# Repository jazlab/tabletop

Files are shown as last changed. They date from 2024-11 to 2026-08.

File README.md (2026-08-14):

# TableTop

TableTop is a [ROS 2](https://docs.ros.org/en/jazzy/index.html)-based robotics
platform for controlling one or more Universal Robots UR5e arms in a monkey
electrophysiology research rig. It runs entirely in [Docker](https://www.docker.com/)
containers and uses [MoveIt 2](https://moveit.picknik.ai/) for motion planning.

The system presents physical objects to a subject, measures their responses
(button presses, eye gaze), delivers rewards, and records synchronized sensor
and robot-state data (via ROS 2 Bag files) for offline analysis. It also ships a
virtual tabletop environment for simulation and system testing, plus
post-processing tools for motion correction, spike sorting, NWB conversion, and
gaze estimation.

## Documentation

**Full documentation lives at <https://jazlab.github.io/tabletop/>.** Start there
for the project overview, setup, usage, and troubleshooting:

- **[Setup](https://jazlab.github.io/tabletop/getting-started/setup/)** — clone,
  configure the host, and bring up the containers.
- **[Real Hardware Setup](https://jazlab.github.io/tabletop/getting-started/real-hardware/)**
  — the TableTop network, URCaps, and remote control.
- **[Usage](https://jazlab.github.io/tabletop/getting-started/usage/)** — build,
  start containers, and run a task.
- **[Design Choices](https://jazlab.github.io/tabletop/design-choices/)** — why
  ROS 2, MoveIt 2, and Docker.
- **[Architecture](https://jazlab.github.io/tabletop/architecture/)** — the
  conceptual dependency map and where to look when something breaks.
- **[Guide](https://jazlab.github.io/tabletop/guide/cli/)** — CLI tooling,
  configuration, the task system, hardware & safety, and troubleshooting.
- **[API Reference](https://jazlab.github.io/tabletop/reference/)** —
  auto-generated for `tabletop_py`, `tabletop_rig`, and `tabletop_tasks`.

The same pages live as Markdown under [`docs/`](docs/) if you prefer to read them
in the repository.

## Quick start

```bash
# Clone with submodules
git clone --recurse-submodules https://github.com/jazlab/tabletop.git
cd tabletop

# Source the environment (puts the tt-* commands on your PATH)
source setup.bash
```

See [Setup](https://jazlab.github.io/tabletop/getting-started/setup/) for the
full host configuration (Docker, `uv`, `.env` generation) and
[Usage](https://jazlab.github.io/tabletop/getting-started/usage/) for building
and launching.

## Contributing

Contributions are welcome. Fork the repo, install the dev dependencies
(`uv sync`) and pre-commit hooks (`pre-commit install`), make your changes on a
branch, and open a pull request. Python follows `ruff` formatting (79-char
lines, Google-style docstrings); pre-commit runs the linters automatically on
commit. Please follow the
[ROS 2 contribution guidelines](https://docs.ros.org/en/jazzy/The-ROS2-Project/Contributing.html).

Notebooks under `notebooks/` are committed **without outputs** — `nbstripout`
clears cell outputs and execution counts on commit, so embedded plots don't
bloat the repo or produce unreadable diffs. If a commit is rejected with
`nbstripout ... files were modified by this hook`, the notebook has just been
stripped in place: `git add` it again and re-commit. Re-running the notebook
locally to restore the outputs is fine; they just don't get committed.

## License

[MIT](LICENSE)

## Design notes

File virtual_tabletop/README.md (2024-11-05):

# Virtual TableTop Model

## Introduction

This directory has code to create a virtual model of the TableTop environment in
Mujoco. It is currently in draft mode and there are several things to do going
forward:
1. Flesh out the rig model with all the parts of the rig.
2. Allow this virtual tabletop to load logs from a session and simulate the
robot, rig, and monkey based on those logs.
3. Adapt the monkey arm model to the geometry of our monkeys.

## Usage

Set up by following these steps:
1. Clone this repo locally.
2. Create a virtual environment to manage dependencies.
3. Install requirements by navigating the this directory and running
   `$ pip install -r requirements.txt`.
4. Run the virtual tabletop model with `$ python run_tabletop.py`.

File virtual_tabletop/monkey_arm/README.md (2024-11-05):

# Model Monkey Arm

This model monkey arm was forked and modified from the Saxena Lab muSim
musculoskeletal model (https://github.com/saxenalab-neuro/muSim).

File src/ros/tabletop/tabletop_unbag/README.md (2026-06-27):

# tabletop_unbag

A generic ROS 2 bag (MCAP) → CSV / image exporter, written in C++. It is a port
of the Python `tabletop_rig.utils.rosbag` module, but runs as a standalone,
dependency-light executable (`unbag`) with no Python / pandas / rclpy at
runtime, and is built to stream very large bags without exhausting memory.

It is **multithreaded**: a single reader thread feeds one consumer thread per
CSV topic and a shared pool of worker threads that decode images in parallel, so
the (CPU-bound) image transcoding scales across all cores. On a 24-core machine
this is roughly a 10× end-to-end speedup over the single-threaded version, while
peak memory stays bounded by back-pressure on the work queues.

## What it does

Given a *bag directory* (the directory that holds the `.mcap` files and
`metadata.yaml`), `unbag` writes one output per topic into an output directory
(by default `<parent of BAG_DIR>/unbag`):

* **Normal messages** are flattened into a per-topic CSV
  (`/eyelink/sample` → `eyelink_sample.csv`). Any message type works — there is
  no per-type code. Nested submessages become dot-separated columns
  (`pose.position.x`) and array / sequence elements become bracket-indexed
  columns (`name[0]`, `position[2]`). Every row carries a `bag_time_ns` column,
  and the columns are the union of every field seen across the topic's messages
  (shorter messages leave trailing columns empty).
* **Image topics** (`sensor_msgs/msg/Image`,
  `sensor_msgs/msg/CompressedImage`) are decoded and saved as image files under
  a per-topic subdirectory (`<topic>/<sec>_<nanosec>.{jpg,png,tiff}`). The `sec`
  and `nanosec` fields are zero-padded to a fixed width (10 and 9 digits) so the
  files sort chronologically under a plain lexicographic sort. When more
  than one frame shares a header stamp (e.g. synchronized cameras), the extra
  frames are kept under a zero-padded suffix
  (`<sec>_<nanosec>_<NNN>.<ext>`) assigned in bag-receive order, so no frame is
  lost and the files still sort chronologically. `--image-format` controls the
  output file format.

## Usage

```bash
# Unbag everything into <parent of BAG_DIR>/unbag
ros2 run tabletop_unbag unbag /path/to/session/bag

# Choose the output directory
ros2 run tabletop_unbag unbag /path/to/session/bag -o /path/to/out

# Only the CSV handler (skip image topics), or only the image handler
ros2 run tabletop_unbag unbag BAG_DIR --handlers csv
ros2 run tabletop_unbag unbag BAG_DIR --handlers image --image-encoding mono8

# Save every image as PNG (lossless) instead of keeping the source format
ros2 run tabletop_unbag unbag BAG_DIR --handlers image --image-format png

# Restrict / exclude topics (mutually exclusive)
ros2 run tabletop_unbag unbag BAG_DIR --topics /joint_states /predicted_markers
ros2 run tabletop_unbag unbag BAG_DIR --exclude-topics /rosout

# Re-run from scratch instead of resuming
ros2 run tabletop_unbag unbag BAG_DIR --overwrite
```

Handler-specific options are namespaced by handler (`--csv-*`, `--image-*`) so it
is clear which handler each one affects; run-wide options have no prefix.

**Common options**

| Flag | Description |
| --- | --- |
| `BAG_DIR` (positional) | Directory containing the bag's `.mcap` files and `metadata.yaml`. Required. |
| `-o, --output-dir DIR` | Where to write outputs. Default: `<parent of BAG_DIR>/unbag`. |
| `--handlers H [H ...]` | Handlers to enable (`csv`, `image`). Topics whose type is not claimed by an enabled handler are skipped. Default: all. |
| `--topics T [T ...]` | Only unbag these topics. Mutually exclusive with `--exclude-topics`. |
| `--exclude-topics T ...` | Unbag all topics except these. Mutually exclusive with `--topics`. |
| `--overwrite` | Delete previously unbagged output for the selected topics before writing. Without it, an interrupted run resumes. |
| `--jobs N` | Worker threads in the shared image-decoding pool (default: number of hardware threads). Each CSV topic additionally runs on its own consumer thread. |
| `--opencv-threads N` | Threads OpenCV uses internally per image decode (default `1`). We already parallelize across images via `--jobs`, so `1` avoids oversubscribing cores; `0` lets OpenCV choose. Tune against `--jobs` for your machine. |
| `--storage-id ID` | Storage plugin override. Default: inferred from `metadata.yaml`; if that file is missing the bag is reindexed first and the id read back from the rebuilt metadata, then falling back to the installed default plugin (`mcap` on a stock Jazzy install). |
| `-v, --verbose` | Log the handler chosen for each topic, topics skipped, and per-topic success/failure counts in the end-of-run summary. |

**`csv` handler options**

| Flag | Description |
| --- | --- |
| `--csv-batch-size N` | Rows buffered in memory before flushing to disk (default 1000). |

**`image` handler options**

| Flag | Description |
| --- | --- |
| `--image-encoding ENC` | Target *color* encoding for decoded images (default `bgr8`; e.g. `rgb8`, `mono8`). |
| `--image-format FMT` | Output *file* format: `keep` \| `png` \| `jpg` \| `tiff` (default `keep`). `keep` preserves the source container (a `CompressedImage` keeps its compression, a raw `Image` is written as PNG); a specific format applies to every image topic (`png` avoids a lossy re-encode of compressed Bayer topics). |

The storage plugin is inferred from the bag's `metadata.yaml`; if that file is
missing or corrupted it is rebuilt with the rosbag2 reindexer and the storage id
read back from the result. `--storage-id` is only needed when that inference is
unavailable or wrong (and seeds the reindexer when no metadata exists). There is
no `--serialization-format` flag: the reader determines each message's input
serialization from the per-topic metadata, and the converter always targets CDR
for the deserializers, so the format is not something the user picks.

After the write pass, `unbag` prints a one-line summary of how many messages were
successfully unbagged versus dropped (a decode/flatten/write failure), with a
per-topic breakdown for any topic that had failures (and for every topic under
`--verbose`). Failures are usually all-or-nothing per topic, so a partial count
is a useful signal that something is off with that topic.

## Architecture

Each message type is routed to a **handler**. Handlers live in `handlers/` and
derive from `MessageHandler` (`handlers/handler.hpp`); a small dispatch in
`unbagger.cpp` picks, per topic, the first handler that claims the message type
(the image handler is checked before the CSV catch-all). Adding support for a
new output type is a matter of adding a handler and registering it.

```text
include/tabletop_unbag/
├── options.hpp            # UnbagOptions, TopicInfo
├── progress_bar.hpp       # tqdm-style progress bar (header-only, no deps)
├── concurrent_queue.hpp   # bounded blocking queue (reader <-> workers)
├── unbagger.hpp           # unbag(): metadata inference + dispatch + the passes
└── handlers/
    ├── handler.hpp        # MessageHandler base (the handler lifecycle)
    ├── csv_handler.hpp
    └── image_handler.hpp
src/
├── main.cpp               # CLI
├── unbagger.cpp           # orchestration + the threaded pipeline
└── handlers/
    ├── csv_handler.cpp    # flattening + pandas-compatible value formatting
    └── image_handler.cpp  # cv_bridge / Bayer decode (thread-safe, atomic writes)
```

### The handler lifecycle (two passes, batched, resumable)

The orchestrator drives every handler through the same lifecycle, which is what
lets it stay type-agnostic:

1. **Preprocess pass** — `preprocess()` is called once per message, but only for
   handlers whose `needs_preprocess()` is true. The CSV handler needs it to
   learn the column set: a `sequence<>` field's length is only known per
   message, so the column union cannot be known without reading every message
   first. It stores only column *names* (O(#columns) memory), not rows. The
   image handler does not need it (each image is independent), so its
   `preprocess()` is a no-op and — when no enabled handler needs the pass — the
   whole pass is skipped. This pass also pushes a topic filter into the storage
   reader so only the CSV topics are read: the bulk of a bag is usually image
   data, and there is no reason to read (or decode) it just to learn columns.
2. **`begin_write()`** — handlers apply the overwrite/resume policy.
3. **Write pass** — `write()` is called once per message; handlers buffer and
   flush in batches (the CSV handler's batch is sized by `--csv-batch-size`), so
   memory stays bounded no matter how many messages a topic has.
4. **`finish()`** — flush and close.

**Interruption / resume.** Because output is flushed incrementally, an
interrupted run leaves valid partial output. Re-running (without `--overwrite`)
picks up where it left off: the CSV handler counts the rows already on disk
(repairing a torn final line) and skips that many messages before appending; the
image handler skips timestamps whose file already exists. `--overwrite` instead
deletes the selected topics' prior output first — the CSV handler removes its
file, and the image handler clears the topic's directory so a re-run with a
different `--image-encoding` cannot leave a mix of old and new formats behind.

### Parallelism and back-pressure

A bag is read once per pass by a single reader thread (rosbag2's reader is
sequential), but the per-message work is fanned out:

* **Across topics.** Each CSV topic gets its own bounded queue and consumer
  thread, so different topics' files are flattened and written concurrently.
  Rows stay in bag order because a topic's messages flow through one FIFO queue
  to one consumer.
* **Across messages, for images.** Image messages from every image topic go to a
  single shared queue drained by a pool of `--jobs` worker threads. Each image is
  decoded, demosaiced and encoded independently and written to its own file, so
  this scales across cores — and image transcoding is by far the most expensive
  part of unbagging a camera-heavy bag. (CSV rows are *not* parallelized within a
  topic: they share one file and must stay ordered, and CSV work is cheap enough
  that one thread per topic already keeps up with the reader.)

The queues are **bounded**, which does double duty: it caps memory (the reader
cannot race ahead and buffer the whole bag), and it makes the reader
self-throttle to the slowest consumer — when the image pool is saturated the
reader simply blocks on `push()` instead of piling up work.

Shutdown is the same on success and on Ctrl-C. A `SIGINT`/`SIGTERM` handler sets
a stop flag; the reader stops, closes the queues, and the workers drain whatever
is already queued and exit before the handlers flush and close. Combined with
atomic image writes (each image is encoded to memory, written to a temp file,
then `rename`d into place) and the CSV torn-line repair, an interrupted run never
corrupts an output file and always resumes cleanly. The input bag is opened
read-only and is never written to.

### Generic flattening

The Python version relies on rclpy's dynamically generated message classes and
`get_fields_and_field_types()`. C++ messages are statically typed, so the CSV
handler instead loads the `rosidl_typesupport_introspection_cpp` description of
each type at runtime and reads the CDR payload directly with Fast CDR (ROS 2
serializes messages as PLAIN_CDR / XCDRv1). This is RMW-independent (it does not
go through `rmw_deserialize`), so it works regardless of the active middleware.
Values are formatted to match pandas' `to_csv` output: shortest round-tripping
floats with a trailing `.0` on integral values, `True`/`False` for booleans, and
RFC 4180 minimal quoting for strings.

### Image decoding

Color conversion goes through **cv_bridge** for uncompressed `Image` messages
and for non-Bayer `CompressedImage` messages, so any target encoding cv_bridge
supports works (set with `--image-encoding`). The one case cv_bridge cannot
handle is a **compressed Bayer** image: the FLIR cameras JPEG-compress the raw
single-channel Bayer mosaic (format e.g. `bayer_rggb8; jpeg compressed
bayer_rggb8`), and cv_bridge infers a compressed image's encoding from its
channel count, so it would mistake the mosaic for `mono8` and never demosaic.
For that case the handler parses the `format` string and demosaics with the
Bayer-aware OpenCV conversion codes (ROS and OpenCV name Bayer patterns from
opposite corners, hence the swapped-looking codes). Uncompressed Bayer is fine
through cv_bridge, which knows the source encoding from `msg.encoding`.

### One intentional difference from the Python version

The Python flattener expands variable-length sequences but, due to a quirk of
its `sequence<...>` type-string check, collapses **fixed-size primitive arrays**
(e.g. `CameraInfo.k`, a `float64[9]`) into a single column holding a numpy
string like `[600. 0. 320. ...]`. This port expands fixed-size arrays the same
way as sequences (`k[0]..k[8]`), which is the more useful and presumably
intended behavior. All other CSV output is byte-for-byte identical to the Python
converter (verified by diffing both on the same bag).

## Building

```bash
tt-build colcon -p tabletop_unbag
# or, directly:
colcon build --packages-select tabletop_unbag
```

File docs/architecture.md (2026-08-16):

# TableTop System Architecture

A conceptual dependency map of the TableTop platform: how the pieces fit
together, who talks to whom, and where to look when something breaks.
Intended for new users, developers, and agents navigating the codebase.

> Scope: the core platform (`bin/`, `compose.yaml`, `src/tabletop_py`,
> `src/ros/tabletop/*`). External forks in `src/ros/modules/` and the
> `virtual_tabletop/` MuJoCo simulation are out of scope.

## 1. The Big Picture

The system is layered. Each layer only reaches *down*:

```text
┌──────────────────────────────────────────────────────────────────┐
│ EXPERIMENTS   tabletop_tasks: ForagingTask, SmoothPursuitTask, … │
│               (YAML task configs → trial generators → trials)   │
├──────────────────────────────────────────────────────────────────┤
│ ORCHESTRATION tabletop_rig Commander node                        │
│               (aggregates interfaces: MoveIt, Teensy, Flic,      │
│                Eyelink, UR dashboard, Sound)                     │
├──────────────────────────────────────────────────────────────────┤
│ DEVICE NODES  one ROS 2 node per device, one Docker container    │
│               per node: ur driver, teensy (micro-ROS), flic,     │
│               eyelink, flir cameras, optitrack, rosbag           │
├──────────────────────────────────────────────────────────────────┤
│ ROS PLUMBING  tabletop_interfaces (msgs/srvs/actions),           │
│               tabletop_description (URDF), tabletop_moveit_config│
├──────────────────────────────────────────────────────────────────┤
│ PURE PYTHON   tabletop_py: gaze ML, flic protocol, utils         │
│               (no ROS dependency; imported by the layers above)  │
├──────────────────────────────────────────────────────────────────┤
│ INFRA         bin/ scripts → compose.yaml services → Docker      │
│               (.env generated by tt-env-gen; setup.bash env)     │
└──────────────────────────────────────────────────────────────────┘
```

All containers share `network_mode: host` and `ipc: host`, so every ROS
node sees every other node regardless of which container it runs in.

## 2. Infrastructure Layer

### 2.1 Environment flow

```text
setup.bash ──(sourced by every script & container entrypoint)──▶ env vars
    │            TABLETOP_DIR, COLCON_WS, ROS_LOG_DIR, ROBOT_IP…
    ▼
tt-env-gen ──▶ .env  (from .env.example; detects FLIR devices and the
    │                 PulseAudio socket; derives the GPU vars from the
    │                 user-set COMMANDER_RUNTIME)
    ▼
tt-compose ──▶ docker compose (compose.yaml reads .env for devices,
                runtimes, mounts)
```

- `setup.bash` is the single source of environment truth. It detects
  host-vs-container via `TABLETOP_CONTAINER`, activates the right uv
  venv (`.venv` host / `.venv.container` container), sources ROS, and
  puts `bin/common` + `bin/host` or `bin/container` on `PATH`.
- `.env` must be regenerated (`tt-env-gen`) whenever hardware changes
  (cameras/Teensy plugged in) because device paths are baked into it, and
  whenever `COMMANDER_RUNTIME` changes because `UV_EXTRA` and the `NVIDIA_*`
  variables are derived from it. The container runtime is opt-in, not
  autodetected — see
  [Configuration](guide/configuration.md#gpu-access-nvidia-container-runtime).

### 2.2 `bin/` scripts — what each one actually runs

| Script | Where | Under the hood |
| --- | --- | --- |
| `host/tt-compose` | host | `tt-env-gen` (if no `.env`) then `docker compose "$@"` |
| `host/tt-env-gen` | host | regenerates `.env` from `.env.example`; scans `/dev/flir/` and PulseAudio; expands `COMMANDER_RUNTIME` into `UV_EXTRA`/`NVIDIA_*` |
| `host/tt-build` | host | `tt-env-gen` then `docker compose run --rm builder tt-build "$@"` |
| `host/tt-attach` | host | `tt-env-gen` then `docker compose run --rm <svc> [/entrypoint.sh] bash` (or `exec` with `-e`); does **not** start the service |
| `host/tt-flir-reset` | host | `tt-env-gen` → stop flir svc → reload udev → `docker compose run --rm flir tt-launch flir_no_sync factory_reset:=true` → restart |
| `container/tt-build` | container | dispatches on `<colcon\|microros\|foxglove>`: colcon (`uv sync` + `colcon build`), microros (PlatformIO `pio run`), foxglove (`npm run package` → `.foxe` to `$TABLETOP_DIR` or `-o` path) |
| `container/tt-launch` | container | case-routes to `ros2 launch <pkg> <name>.launch.py`, sets per-target `ROS_LOG_DIR` |
| `container/tt-kill-ros` | container | `pkill -f ros` |
| `common/tt-clean` | both | `rm -rf` of build/install/log/cache dirs by flag |

Host configuration for real hardware (udev rules, USB buffer size, CPU governor,
the TableTop network, URCaps) is no longer shipped as `scripts/configure/`
scripts; it is documented as Ubuntu 24.04 procedures in
[Real Hardware Setup](getting-started/real-hardware.md).

### 2.3 Compose services × profiles

| Service | Profile(s) | Command | Devices / special |
| --- | --- | --- | --- |
| `ros-base` | template | — (extends-only) | bind-mounts repo at `/tabletop`; parent of all ROS services, never run directly |
| `commander` | commander | `tt-launch commander` | `$COMMANDER_RUNTIME` (GPU when set to `nvidia`), PulseAudio, bags mount |
| `ur` / `ur-mock` | real / sim | `tt-launch dual_ur robot_mode:=real\|mock` | rtprio ulimits |
| `teensy` / `teensy-sim` | real / sim | `tt-launch teensy simulate:=false\|true` | `$TEENSY_DEV` serial |
| `flic` / `flic-sim` | real / sim | `tt-launch flic simulate:=false\|true` | `NET_ADMIN` (BLE sniffing) |
| `eyelink` / `eyelink-sim` | real / sim | `tt-launch eyelink simulate:=…` | bags mount |
| `flir` | real | `tt-launch flir_synchronized` | `$FLIR_DEV_0..5` USB devices |
| `optitrack` | real | `tt-launch optitrack` | |
| `rviz`, `foxglove` | real, sim | `tt-launch rviz\|foxglove` | rviz renders to noVNC display |
| `novnc` | real, sim | X11+VNC server | browse to `localhost:<NOVNC_PORT>/vnc.html` |
| `builder` | builder | — (set at run time) | privileged, `/dev`, platformio cache volume; target of host `tt-build` |
| `dev` | dev | `sleep infinity` | the Dev Container; everything mounted |

A typical real-hardware session: `tt-compose --profile=real up` starts
ur + teensy + flic + eyelink + optitrack + flir + rviz + novnc, then
`tt-compose run --rm commander tt-launch tasks task:=…` runs a commander
container on top.

## 3. ROS Runtime Graph

Who talks to whom at runtime (solid = topic, dashed = service/action):

```mermaid
graph LR
    subgraph commander container
        CMD[commander node]
    end
    subgraph device containers
        UR[ur driver + controller_manager]
        TEENSY[teensy micro-ROS agent ⇄ Teensy 4.1]
        FLIC[flic node]
        EYE[eyelink node]
        FLIR[cam_sync node]
        OPTI[optitrack_driver]
        BAG[rosbag recorder]
    end

    TEENSY -- "teensy/sensor (TeensySensor)" --> CMD
    CMD -. "teensy/set_arm_lock, set_reward,<br>set_smartglass, set_solenoid" .-> TEENSY
    CMD -. "flic/response_time (action)" .-> FLIC
    CMD -. "eyelink/smooth_pursuit (action)" .-> EYE
    EYE -- "eyelink samples" --> BAG
    CMD -. "left|right dashboard srvs,<br>controller_manager srvs" .-> UR
    UR -- "joint_states, robot_description" --> CMD
    CMD -- "trajectory execution (MoveIt)" --> UR
    FLIR -- "cam_sync/<cam>/image_raw, meta" --> BAG
    OPTI -- "rigid body poses" --> BAG
```

Key edges:

- **Safety loop**: Teensy firmware publishes `teensy/sensor` (at a configurable
  rate); `TeensyInterface` (inside Commander) gates every robot motion through
  `safe_to_execute`. The safety-laser field is always enforced; the arm-lock
  check (both restraints seated) is gated by the
  `safe_to_execute.require_arm_locks` parameter in `commander.yaml`, which
  defaults to `false` (laser-only) — set it `true` to also require the arm
  locks. See [Hardware & Safety](guide/hardware.md#safety-interlock).
- **Hardware sync**: the Teensy emits a hardware trigger pulse wired to
  the FLIR cameras' Line0, so all cameras expose simultaneously; the
  synchronized driver stamps grouped frames identically.
- **MoveIt runs inside the Commander process** (`moveit_py`), not as a
  separate `move_group` node — planning is in-process, execution goes
  to the UR `controller_manager` action servers.

## 4. Launch & Configuration

### 4.1 Launch hierarchy

There is **no monolithic aggregator launch file**. The old `rig.launch.py`
(which bundled every subsystem behind `*_launch:=true|false` toggles) was
retired to `deprecated/launch/rig.launch.py`; each subsystem now runs in its
own Compose service, launched by its own `tt-launch <target>` (see §2.3). The
only launch file that *includes* others is `tasks.launch.py`, which now pulls in
just the commander and (optionally) the recorder:

```text
tasks.launch.py (tabletop_tasks)         task:=<name> ⇒ coro_config=config/<name>.yaml
├── commander.launch.py (tabletop_rig)   → commander node (+ moveit_cpp config),
│                                           runs run_tasks(coro_config)
└── rosbag.launch.py (tabletop_rig)       → ros2 bag record (topics from rosbag.yaml)
                                            [only if rosbag:=true — see note below]

# Each of the following is its own tt-launch target / Compose service:
commander.launch.py        → commander node alone (no task)
dual_ur.launch.py          → ur driver stack (both arms)
    └── dual_rsp.launch.py (tabletop_description) → robot_state_publisher (URDF)
teensy.launch.py           → micro_ros_agent | mock_teensy (simulate:=true)
flic.launch.py             → flic node
eyelink.launch.py          → eyelink node
optitrack.launch.py        → mocap4r2 lifecycle driver
flir.launch.py             → per-camera CameraDriver components (unsynchronized)
flir_synchronized.launch.py→ SynchronizedCameraDriver component
flir_calibrate.launch.py   → FLIR calibration capture
rviz.launch.py             → rviz2 (waits for robot_description)
rosbag.launch.py           → ros2 bag record (topics from rosbag.yaml)
moveit.launch.py (tabletop_moveit_config) → standalone move_group + rviz (debug only)
```

So a session is: a Compose profile brings up the device services
(`dual_ur`, `teensy`, `flic`, `eyelink`, `optitrack`, `flir`, `rviz`), then
`tt-launch tasks …` starts a commander (and, with `rosbag:=true`, a recorder)
on top of them.

> **Note — `rosbag` default.** `tasks.launch.py` declares `rosbag` with
> `default_value="false"`, so recording is **off** unless you pass
> `rosbag:=true`.

### 4.2 Config file → consumer map

| Config | Consumed by | Drives |
| --- | --- | --- |
| `tabletop_rig/config/commander.yaml` | commander.launch.py → Commander node | all interface parameters (see §5.3) |
| `tabletop_rig/config/flir_synchronized.yaml` | flir_synchronized.launch.py | camera list, serials, trigger/chunk settings, poses |
| `tabletop_rig/config/flir.yaml`, `blackfly_s.yaml` | flir.launch.py | unsynchronized per-camera params |
| `tabletop_rig/config/dual_controllers.yaml` | dual_ur.launch.py → controller_manager | left/right controller definitions |
| `tabletop_rig/config/optitrack.yaml` | optitrack.launch.py | server address, ports, QoS |
| `tabletop_rig/config/rosbag.yaml` | rosbag.launch.py | recorded topics/services, bag size |
| `tabletop_rig/config/object_reset/*.yaml` | Commander reset_object requests | reset motion parameters |
| `tabletop_tasks/config/<task>.yaml` | tasks.launch.py → run_tasks coroutine | task class + kwargs + trial generator |
| `tabletop_description/config/*_calibration.yaml` | dual_rsp.launch.py | per-arm UR kinematics |
| `tabletop_moveit_config/config/*.yaml` | commander.launch.py, moveit.launch.py | planners, limits, controllers |

### 4.3 Parameter flow (config → code)

```text
config/commander.yaml
  └─ launch ParameterFile ─▶ Commander node parameters (flat, dot-separated)
       └─ BaseNode.param("x.y.z") / get_nested_parameters(prefix)
            └─ BaseInterface.param(name) — resolves "<iface_prefix>.<name>"
               with fallback to "common_<kind>_interface.<name>"
```

Example: `left_ur_interface.namespace` is read by the left
`URInterface`; anything it doesn't override falls back to
`common_ur_interface.*`. The same common/override pattern appears in
`flir_synchronized.yaml` (`camera_params_common` vs `camera_params`)
and task configs.

## 5. Package & Code-Level Dependencies

### 5.1 Package import graph

```mermaid
graph TD
    TP[tabletop_py<br/>pure Python] --> RIG[tabletop_rig]
    TP --> TASKS[tabletop_tasks]
    IF[tabletop_interfaces<br/>msgs/srvs/actions] --> RIG
    IF --> FW[src/microros/tabletop_teensy<br/>firmware]
    RIG --> TASKS
    DESC[tabletop_description] -.URDF via launch.-> RIG
    MVC[tabletop_moveit_config] -.SRDF/planner cfg via launch.-> RIG
    MODS[src/ros/modules/*<br/>external forks] -.runtime deps.-> RIG
    UNBAG[tabletop_unbag<br/>C++ bag→CSV/image tool] -.reads recorded bags offline.-> BAG[(rosbag)]
```

- `tabletop_py` never imports ROS. `tabletop_rig` is the only package
  that wraps it in ROS nodes. `tabletop_tasks` only consumes the
  `Commander`; it never touches devices directly.
- `tabletop_unbag` is a **standalone** C++ `ament_cmake` package (built by the
  normal `tt-build colcon`): it depends only on rosbag2 / sensor_msgs /
  cv_bridge / Fast CDR, not on the other tabletop packages, and produces the
  `unbag` executable for offline bag→CSV/image export. It is the dependency-light
  port of (and supersedes) the legacy Python `tabletop_rig/utils/rosbag.py`
  (`rosbag_to_csv`) — see §5.5.
- `src/microros/` is `COLCON_IGNORE`d — firmware is built by
  PlatformIO (`tt-build microros`), not colcon, but it *implements*
  the `tabletop_interfaces` services in C.
- The **Teensy** firmware (`src/microros/tabletop_teensy`) is the only
  micro-controller firmware, launched via `teensy.launch.py` (micro-ROS agent).
  An earlier, incomplete **Flic Micro** (ESP32) firmware was retired — it now
  lives in `deprecated/flic-button/tabletop_flic_micro/`, superseded by the
  in-process scapy BLE sniffer in the `flic` node.

### 5.2 tabletop_rig internals

Nodes (`tabletop_rig/nodes/`):

| Node | Entry point | Role |
| --- | --- | --- |
| `Commander` | `commander` | orchestrator; owns all interfaces; runs task coroutine |
| `Flic` | `flic` | BLE button → `flic/response_time` action |
| `Eyelink` | `eyelink` | eye tracker samples + `eyelink/smooth_pursuit` action |
| `MockTeensy` | `mock_teensy` | simulates firmware topics/services |
| `MockDashboardClient` / `MockRobotStateHelper` | `mock_*` | simulate UR driver helpers in mock mode |
| `SystemCheck` | `system_check` | live diagnostics (e.g. FLIR sync check) |

Interface composition inside the Commander:

```text
Commander (BaseNode)
 ├── TeensyInterface         teensy srv clients + sensor subscription
 ├── FlicInterface           flic action client
 ├── EyelinkInterface        eyelink action client
 ├── SoundInterface          fluidsynth audio feedback
 ├── MoveItInterface         one shared instance (MoveItPy + planning scene)
 └── ManipulationContextManager ×N   one per arm (from robot_interface_names)
       ├── URInterface              dashboard + recovery state machine
       └── ObjectManipulationInterface  pick/present/return state machine,
              holds a reference to the shared MoveItInterface
```

Every interface extends `BaseInterface`; the relationship is **composition,
not a single linear inheritance chain**:

```text
BaseInterface
 ├── MoveItInterface              MoveItPy, planning scene, collision objects, ACM
 ├── PlanAndExecuteInterface      plan/execute + trajectory cache
 │     └── ObjectManipulationInterface   (composes a MoveItInterface by reference)
 ├── URInterface
 ├── TeensyInterface / FlicInterface / EyelinkInterface / SoundInterface
 └── ManipulationContextManager   (bundles a URInterface + ObjectManipulationInterface)
```

- `ObjectManipulationInterface` is a pick/present/return state machine
  (`ManipulationState` enum); invalid transitions raise
  `StateTransitionError` (see `exceptions.py` for the full hierarchy).
- `PlanAndExecuteInterface` consults the trajectory cache
  (`trajectory_cache*.py`, LMDB + KD-tree fuzzy lookup) before
  re-planning.
- `executors.py` provides the asyncio-bridging executors. Note the
  hard-won lessons (see [Troubleshooting → Commander signal
  handling](guide/troubleshooting.md#commander-signal-handling)): the
  Commander must use the thread-based executor, and the UR driver must
  run in a separate process from the Commander.

### 5.3 tabletop_tasks internals

```text
run.py: run_tasks(commander, config_file)     ← coroutine injected via
  loads tasks: [{class, kwargs}] from YAML       commander.launch.py
    └─ tasks/base.py
         BaseTask(run)                 — owns a Commander reference
         BaseObjectInteractionTask     — generic trial loop:
            trial_generator → TrialSpec → run_trial() → TrialFeedback
       tasks/{foraging,present,smooth_pursuit,dummy}.py
    └─ trial_generators/
         BaseTrialGenerator (iterator + send() feedback protocol)
         {ordered,random}_choice_alternating.py
```

### 5.4 tabletop_py usage map

| Module | Used by |
| --- | --- |
| `utils/common.py` (yaml/dict helpers) | rig `nodes/base`, `utils/logging`, `utils/ros`, interfaces, tasks `run.py` |
| `utils/mesh.py` | rig `interfaces/moveit/object_manipulation.py` (collision meshes) |
| `flic/scapy_client.py` | rig `nodes/flic.py` |
| `gaze/*` (edf, preprocess, models, train…) | rig `nodes/eyelink.py` + offline CLI tools (`tt-gaze-*` entry points in `pyproject.toml`) |

### 5.5 Data export (bag → CSV / images)

Sessions are recorded as MCAP rosbags (`rosbag.launch.py`, topics from
`rosbag.yaml`). **`tabletop_unbag`** turns a bag into per-topic CSVs and decoded
image files:

| Converter | Invocation | Notes |
| --- | --- | --- |
| `tabletop_unbag` (`unbag`) | `ros2 run tabletop_unbag unbag BAG_DIR` | Current tool. Standalone C++: no Python/pandas at runtime, multithreaded, streaming (bounded memory), resumable. CSV is byte-identical to the legacy Python output (one intentional difference: fixed-size primitive arrays are expanded to indexed columns). |
| `tabletop_rig/utils/rosbag.py` (`rosbag_to_csv`) | `ros2 run tabletop_rig rosbag_to_csv` | **Legacy.** The Python version `unbag` was ported from; its `tt-launch` target was removed and it is slated for retirement (Wave 2 — gaze calibration to use `tabletop_unbag`; see `fix-plan.md`). |

`unbag` routes each message type to a *handler* (CSV catch-all, image decode via
cv_bridge), reading the CDR payload generically with
`rosidl_typesupport_introspection_cpp` + Fast CDR. See
`tabletop_unbag/README.md` and [Usage → Converting recorded bags](getting-started/usage.md#converting-recorded-bags)
for the full option set.

## 6. Where to Look When Something Breaks

| Symptom | Start here | Then |
| --- | --- | --- |
| `tt-*` command not found | `source setup.bash` | `bin/` PATH logic in setup.bash |
| Container can't see camera/Teensy | `tt-env-gen` then `tt-compose ps` | `.env` `FLIR_DEV_*`/`TEENSY_DEV`, `compose.yaml` devices |
| Robot won't move, no error | Teensy safety loop | `interfaces/teensy.py: safe_to_execute`; safety laser (and arm locks if `require_arm_locks:=true`) |
| "Joint outside bounds" on start | robot was manually moved | [Troubleshooting → Robot](guide/troubleshooting.md#robot-ur5e) |
| Planning fails / slow | trajectory cache + planner config | `interfaces/moveit/plan_and_execute.py`, `tabletop_moveit_config/config/` |
| Pick/place stuck in weird state | manipulation state machine | `interfaces/moveit/object_manipulation.py` (`ManipulationState`) |
| Cameras out of sync / missing frames | `ros2 run tabletop_rig system_check` | `flir_synchronized.yaml` trigger settings, Teensy sync pulse |
| `flic` fails with `No such device`, no `/flic` node | `ls /sys/class/bluetooth` on the **host** | no `hci0` — load `btusb`/`btintel`, see [Real Hardware → Bluetooth adapter](getting-started/real-hardware.md#bluetooth-adapter-flic-buttons) |
| Flic button not responding | flic container logs | [Troubleshooting → Flic buttons](guide/troubleshooting.md#flic-buttons) |
| Task behaves wrong | the task's YAML config | `tabletop_tasks/config/<task>.yaml` → task class kwargs |
| CSV/images missing or malformed after a session | the bag exporter | `ros2 run tabletop_unbag unbag BAG_DIR -v` (per-topic failure counts); §5.5 |
| Commander hangs on shutdown | signal handling notes | [Troubleshooting → Commander signal handling](guide/troubleshooting.md#commander-signal-handling) |
| No sound in container | PulseAudio mount | `tt-env-gen` PULSE_* detection, `compose.yaml` commander mounts |

## 7. Related Documents

- `README.md` — high-level project overview and entry point into this docs site
- `docs/guide/troubleshooting.md` — battle-tested troubleshooting notes
- `docs/known-issues.md` — discrepancies found during documentation review

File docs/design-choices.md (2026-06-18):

# Design Choices

The major architectural decisions behind TableTop, and the rationale for each.

## ROS 2

The project uses [ROS 2](https://docs.ros.org/en/jazzy/index.html) as the main
framework for controlling the UR5e robot and for recording/compiling sensor and
state-space data. Reasons for choosing ROS 2 over a bespoke solution:

* ROS 2 provides a powerful, flexible framework for building complex
    distributed systems with many interdependent components.
* Its message-based architecture makes communication between nodes
    straightforward.
* It has built-in recording and playback via ROS 2 Bag files.
* It provides many packages for customizing each stage of the robot-control
    pipeline.
* Universal Robots ships a robust ROS 2 driver for the UR5e, making integration
    with existing ROS 2 pipelines easy.
* It supports real-time kernels, useful for ensuring critical tasks execute on
    time (e.g. closed-loop motion control).

A bespoke solution would require significant development time and would limit
the ability to incorporate new features such as feedback-driven robot control.

## MoveIt 2

The project uses [MoveIt 2](https://moveit.picknik.ai/main/index.html) for
planning and control of the UR5e:

* MoveIt 2 provides utilities for planning and control, plus real-time
    visualization of the robot and environment state.
* It supports a variety of motion controllers and planning algorithms, each
    with its own customization options.
* The Universal Robots ROS 2 driver ships with MoveIt 2 functionality
    pre-configured.

The alternative (sending URScript commands directly to the robot) limits control
to what the robot's software provides, which does not support complex scenario
planning or feedback control.

## Docker

The project runs entirely in [Docker](https://www.docker.com/) containers, which
provide:

* OS-agnostic development and deployment environments, accessible regardless of
    host hardware.
* An isolated environment for each component of the software stack, each with
    its own dependencies and configuration already set up.
* A consistent, reproducible environment for development and deployment.
* A quick way to run the software without installing and configuring
    dependencies by hand.

Developing on bare metal would require manual dependency management and
configuration, which is time-consuming, error-prone, and often system-breaking.
It also limits platform compatibility, since ROS 2 is optimized for Ubuntu. The
UR Simulator additionally cannot be installed on Apple Silicon and must be run
in a container.

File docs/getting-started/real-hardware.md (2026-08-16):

# Real Hardware Setup

This page covers the one-time configuration needed to drive the **real**
hardware (the network, the UR5e robot, and the rig computers). If you only
intend to run in simulation (`robot_mode:=mock`), you can skip this page
entirely.

Before starting, make sure you have completed the [Setup](setup.md) steps
(clone, `source setup.bash`, `tt-env-gen`).

!!! note "Tested on Ubuntu 24.04"
    The real hardware has only been tested with a host machine running
    **Ubuntu 24.04**. The command-line examples on this page are written for
    Ubuntu 24.04; on another distribution use the equivalent tools (or the
    graphical settings). Where an approach differs across systems it is called
    out inline.

!!! note "Teensy firmware"
    Building and flashing the Teensy micro-controller firmware is covered in
    [Setup → Firmware](setup.md#firmware).

## Host configuration (Ubuntu 24.04)

These steps prepare the host for device access and real-time control. They are
the concrete commands that work on Ubuntu 24.04; on another distribution use the
equivalent mechanism (the udev rules themselves are distro-independent).

### Device access (udev rules)

The Teensy / Flic Micro and the FLIR cameras need udev rules so the containers
can open them — and so each FLIR camera gets a stable `/dev/flir/<serial>`
symlink. Create the rule files under `/etc/udev/rules.d/` and reload:

```bash
# Teensy / Flic Micro (vendor 16c0, plus the 1fc9 BLE dongle)
sudo tee /etc/udev/rules.d/00-teensy.rules > /dev/null <<'EOF'
ATTRS{idVendor}=="16c0", ATTRS{idProduct}=="04*", ENV{ID_MM_DEVICE_IGNORE}="1", ENV{ID_MM_PORT_IGNORE}="1"
ATTRS{idVendor}=="16c0", ATTRS{idProduct}=="04[789a]*", ENV{MTP_NO_PROBE}="1"
KERNEL=="ttyACM*", ATTRS{idVendor}=="16c0", ATTRS{idProduct}=="04*", MODE:="0666", RUN:="/bin/stty -F /dev/%k raw -echo"
KERNEL=="hidraw*", ATTRS{idVendor}=="16c0", ATTRS{idProduct}=="04*", MODE:="0666"
SUBSYSTEMS=="usb", ATTRS{idVendor}=="16c0", ATTRS{idProduct}=="04*", MODE:="0666"
KERNEL=="hidraw*", ATTRS{idVendor}=="1fc9", ATTRS{idProduct}=="013*", MODE:="0666"
SUBSYSTEMS=="usb", ATTRS{idVendor}=="1fc9", ATTRS{idProduct}=="013*", MODE:="0666"
EOF

# FLIR cameras (vendor 1e10 / 1724; creates /dev/flir/<serial> symlinks)
sudo tee /etc/udev/rules.d/40-flir.rules > /dev/null <<'EOF'
SUBSYSTEM=="usb", ATTRS{idVendor}=="1e10", MODE="0666" SYMLINK+="flir/%s{serial}"
SUBSYSTEM=="usb", ATTRS{idVendor}=="1724", MODE="0666" SYMLINK+="flir/%s{serial}"
EOF

# Reload and apply
sudo udevadm control --reload
sudo udevadm trigger
```

PlatformIO also ships
[generic board udev rules](https://docs.platformio.org/en/latest/core/installation/udev-rules.html);
the custom Teensy rule above replaces them. After plugging or unplugging a
device, re-run `tt-env-gen` so Docker re-maps it.

### Bluetooth adapter (Flic buttons)

The `flic` node sniffs BLE by opening a raw HCI socket on the host's Bluetooth
controller — `hci0` by default (the node's `device_id` parameter selects
`hciN`). Because all containers share the host network stack, the controller
must already exist **on the host** before you start the `real` profile.
Confirm it does:

```bash
ls /sys/class/bluetooth/     # expect: hci0
```

If that directory is empty, the adapter has not been initialized and the `flic`
container will fail with `No such device` (and no `/flic` node will appear in
the ROS graph). Having the hardware physically present is not enough — the
kernel drivers must be loaded and bound to it. Check what the kernel saw:

```bash
lsusb | grep -i bluetooth                    # is the controller enumerated?
dmesg | grep -iE 'bluetooth|btusb|btintel'   # did a driver bind to it?
rfkill list bluetooth                        # soft/hard blocked?
```

Load the drivers manually if they are missing — `btusb` is the generic USB
transport, plus the vendor module for your controller:

```bash
sudo modprobe btusb
sudo modprobe btintel      # Intel (e.g. AX200/AX201/AX211)
# other vendors: btrtl (Realtek), btbcm (Broadcom), btmtk (MediaTek)

sudo rfkill unblock bluetooth   # only if rfkill reported a soft block
ls /sys/class/bluetooth/        # hci0 should now be listed
```

Then restart the Flic container so the client re-opens the adapter:

```bash
tt-compose --profile=real restart flic
```

!!! note "Usually a one-off, but verify across a reboot"
    Once the modules have been loaded, the kernel normally autoloads them on
    subsequent boots and `hci0` comes back on its own. Reboot and re-run the
    `ls /sys/class/bluetooth/` check to confirm. If the adapter does **not**
    come back, force the modules to load at boot:

    ```bash
    sudo tee /etc/modules-load.d/bluetooth.conf > /dev/null <<'EOF'
    btusb
    btintel
    EOF
    ```

This is a host/Linux initialization issue rather than a TableTop one, so the
same check applies to any distribution — only the driver-loading commands are
Ubuntu-flavoured. Note that a *present* `hci0` can still be unusable if the host
BlueZ stack is holding it; see
[Troubleshooting → Flic buttons](../guide/troubleshooting.md#flic-buttons).

### USB buffer size (FLIR cameras)

FLIR cameras stream large frames and need a bigger USBFS buffer than the kernel
default. Raise `usbcore.usbfs_memory_mb` for the current session and persist it
via GRUB:

```bash
# Current session (effective immediately)
sudo sh -c 'echo 5000 > /sys/module/usbcore/parameters/usbfs_memory_mb'

# Persist across reboots (GRUB)
sudo tee /etc/default/grub.d/99-usbfs-memory.cfg > /dev/null <<'EOF'
GRUB_CMDLINE_LINUX_DEFAULT="$GRUB_CMDLINE_LINUX_DEFAULT usbcore.usbfs_memory_mb=5000"
EOF
sudo update-grub
```

On a distro without `update-grub`, add `usbcore.usbfs_memory_mb=5000` to the
kernel command line through your bootloader's mechanism instead.

### CPU governor (real-time control)

For deterministic real-time robot control, disable CPU frequency scaling by
pinning the CPU to the `performance` governor — the setup
[recommended by the `ur_robot_driver` real-time guide](https://docs.universal-robots.com/Universal_Robots_ROS2_Documentation/doc/ur_client_library/doc/real_time.html).
Any mechanism that pins the governor works; the
[`cpufrequtils`](https://manpages.ubuntu.com/manpages/noble/man1/cpufreq-info.1.html)
approach below (listed under [Requirements](setup.md#requirements)) is just one
example, shown for Ubuntu/Debian:

```bash
sudo apt install -y cpufrequtils
sudo systemctl disable ondemand || true
echo 'GOVERNOR=performance' | sudo tee /etc/default/cpufrequtils
sudo systemctl enable --now cpufrequtils
```

Tools with equivalent functionality on other distributions include:

- [`cpupower`](https://www.kernel.org/doc/html/latest/admin-guide/pm/cpufreq.html)
  — `sudo cpupower frequency-set -g performance`; ships with the kernel tools
  package (`linux-tools-common`/`linux-tools-$(uname -r)` on Debian/Ubuntu,
  `kernel-tools` on Fedora/RHEL).
- [TuneD](https://tuned-project.org/) — apply a real-time-oriented profile such
  as `latency-performance` (`sudo tuned-adm profile latency-performance`),
  common on Fedora/RHEL.

### Real-time kernel (optional, recommended)

The same
[`ur_robot_driver` real-time guide](https://docs.universal-robots.com/Universal_Robots_ROS2_Documentation/doc/ur_client_library/doc/real_time.html)
recommends running a real-time or low-latency kernel for the best control
performance. On Ubuntu 24.04 the low-latency kernel is a drop-in install:

```bash
sudo apt install -y linux-lowlatency
sudo reboot
```

Confirm the running kernel after rebooting with `uname -a` (it should report
`lowlatency`). For a fully preemptible `PREEMPT_RT` kernel, see
[Ubuntu's real-time kernel](https://ubuntu.com/real-time); on other
distributions install that distro's real-time or low-latency kernel package.

## The TableTop network

The host, the UR5e robot control box(es), and the other rig computers (the
EyeLink and OptiTrack hosts) all communicate over a single wired LAN — the
**TableTop network** (it carries more than just the robots, so it is the local
network for the whole rig, not a "robot network").

### Addressing

Every device on the network gets a static IPv4 address in the same `/24` subnet.
The defaults (overridable via `setup.bash`) put everything on `192.168.13.0/24`:

| Device | Variable (in `setup.bash`) | Default |
| --- | --- | --- |
| Host (this machine) | `REVERSE_IP` | `192.168.13.10` |
| Robot / right arm | `ROBOT_IP` / `RIGHT_ROBOT_IP` | `192.168.13.20` |
| Left arm | `LEFT_ROBOT_IP` | `192.168.13.21` |
| EyeLink / OptiTrack hosts | — | pick free addresses in the same subnet |

The host address (`REVERSE_IP`) and each robot address (`ROBOT_IP`) **must share
the same first three octets** — i.e. live in the same `/24` subnet — or the UR
driver cannot reach the robot. The simulator uses a separate `192.168.12.0/24`
subnet (the `SIM_*` variables) and needs no physical network.

### Connecting the devices (network switch)

This configuration assumes an **Ethernet switch** bridges all the devices into
one LAN. Any unmanaged gigabit switch is sufficient. With a standard Ethernet
cable each, connect:

- the host machine,
- each UR5e control box,
- the EyeLink host PC,
- the OptiTrack host PC,

to a port on the switch. The switch simply forwards traffic between the devices;
no router or DHCP server is required, because every device uses a static
address.

### Assigning the host's static IP

**Graphical (GNOME / Ubuntu Settings).** Open **Settings → Network**, click the
gear next to the wired connection, open the **IPv4** tab, set **Method** to
**Manual**, and add the address `192.168.13.10` with netmask `255.255.255.0`
(leave the gateway blank). Apply, then toggle the connection off and on. Any
network-settings UI on your OS can do the same thing.

**Command line (Ubuntu, non-persistent).** Add the address directly to the
ethernet interface (find yours with `ip link`, then replace `<iface>`):

```bash
sudo ip addr add 192.168.13.10/24 dev <iface>
```

This lasts until the next reboot. To make it persistent, use the graphical
settings above,
[`nmcli`](https://networkmanager.dev/docs/api/latest/nmcli.html), or a
[netplan](https://netplan.io/) file under `/etc/netplan/`.

### Firewall

If you run a host firewall (e.g. [`ufw`](https://help.ubuntu.com/community/UFW)),
make sure it does not block traffic on the TableTop subnet — the UR driver and
the rig computers must reach the host on several ports. Either allow the subnet
or disable the firewall while on the rig network:

```bash
sudo ufw allow from 192.168.13.0/24   # allow the local subnet
# or, to turn the firewall off entirely:
sudo ufw disable
```

## UR5e robot

### Setting the robot IP address

With the network in place, set a static IP on the robot via the Teach Pendant:

1. Click the "hamburger" (menu) icon in the top-right corner of the window.
2. Click **Settings**.
3. Go to **System → Network**.
4. Change the network method to **Static Address**.
5. Fill out the fields with the following values (leave the rest at default):
    * **IP Address**: `ROBOT_IP` (e.g. `192.168.13.20`)
    * **Subnet Mask**: `255.255.255.0`
6. Click **Apply**.

### Installing and configuring the `external_control` URCap

The `external_control` URCap is required to command the robot from the host
machine (and therefore from the Docker containers). Copy
`share/externalcontrol-1.0.5.urcap` to the robot's `/programs` directory over
SSH (this needs SSH access to the robot as `root`):

```bash
scp share/externalcontrol-1.0.5.urcap root@$LEFT_ROBOT_IP:/programs
scp share/externalcontrol-1.0.5.urcap root@$RIGHT_ROBOT_IP:/programs
```

Install the copied URCap on the robot using the Teach Pendant:

1. In the **Settings** menu, go to **System → URCaps**.
2. Click the **+** icon and select the URCap file to install (e.g.
    `external_control.urcap`).
3. Click **Restart**. This restarts the robot and loads the new URCap.

*Repeat for each URCap you wish to use.*

Now configure the URCap with the appropriate IP settings:

1. In the **Installation** tab, go to **URCaps → External Control**.
2. Fill out the fields with the following values:
    * **Host IP**: `REVERSE_IP`
    * **Custom Port**: `50002`
    * **Host Name**: `REVERSE_IP`

Finally, create a program that uses the URCap:

1. Click **New → Program** at the top of the window to open the **Program** tab.
2. Click **URCaps → External Control** in the left sidebar to add the
    `external_control` URCap to the program.

Save the program and installation with **Save → Save All**. Save the program
as `external_control.urp` and the installation as `default.installation`, so
the commander loads the correct program and installation when the rig starts.

### Enabling Remote Control Mode

**Remote Control Mode** must be enabled on the Teach Pendant in order to
command the robot through the `external_control` URCap:

1. In the **Settings** menu, go to **System → Remote Control**.
2. Click **Enable**.
3. Click **Exit** to leave the settings menu.
4. Click the **Local** button in the top-right corner of the window.
5. Select **Remote Control** from the dropdown.

*You do not need to do this for the simulator.*

## EyeLink and OptiTrack computers

The EyeLink eye tracker and the OptiTrack motion-capture system each run on
their own dedicated host computer with vendor software; the TableTop host
connects to them over the network and reads their data through ROS nodes. This
is an overview — follow the vendor documentation for the authoritative setup.

### OptiTrack (Motive)

- Run [Motive](https://docs.optitrack.com/) on the OptiTrack host PC and attach
  that PC to the [TableTop network](#the-tabletop-network).
- In Motive, enable **data streaming** (NatNet), stream the rigid body you want
  to track (the rig expects one named `ground` by default), and note the
  server's IP and command/data ports.
- Point the rig's `optitrack_driver` at the server in
  `tabletop_rig/config/optitrack.yaml` (`server_address`,
  `server_command_port`, `server_data_port`, `connection_type`,
  `rigid_body_name`). The defaults expect Motive at `192.168.13.40` on NatNet
  ports `1510`/`1511`.
- See the OptiTrack [Motive](https://docs.optitrack.com/) and
  [NatNet SDK](https://docs.optitrack.com/developer-tools/natnet-sdk)
  documentation for camera calibration and streaming details.

### EyeLink

- Run the SR Research **EyeLink Host PC** software on the EyeLink host computer.
  The rig's `eyelink` node connects to it through `pylink` (from the EyeLink
  Developers Kit).
- By SR Research convention the Host PC is reached over a dedicated Ethernet
  link, typically at `100.1.1.1` with the connecting (Display) PC at
  `100.1.1.2`; configure the relevant host interface accordingly for your setup.
- Install the **EyeLink Developers Kit**, which provides `pylink` and the
  `edf2asc` converter used by the gaze tools. See the
  [SR Research support site](https://www.sr-research.com/support/) for the
  installation packages and EyeLink documentation (account required).

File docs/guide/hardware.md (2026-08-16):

# Hardware & Safety

Each device runs as its own ROS 2 node in its own Docker container. Because all
containers share the host network and IPC, they form a single ROS graph. See
[Architecture §3](../architecture.md) for the runtime topic/service graph.

## Devices

| Device | Node / driver | Role |
| --- | --- | --- |
| UR5e arm(s) | `ur_robot_driver` + `controller_manager` | motion execution (left/right) |
| Teensy 4.1 | micro-ROS agent ⇄ firmware | arm locks, safety laser, reward, smartglass pane, sync pulse, gloves |
| Flic buttons | `flic` node (scapy BLE sniffer) | subject response device |
| EyeLink | `eyelink` node | eye-gaze samples + smooth-pursuit action |
| FLIR cameras | `cam_sync` (SynchronizedCameraDriver) | hardware-synchronized video |
| OptiTrack | `optitrack_driver` (mocap4r2) | rigid-body poses |

For the one-time setup of the EyeLink and OptiTrack host computers (and the
network that connects them to the host), see
[Real Hardware Setup](../getting-started/real-hardware.md#eyelink-and-optitrack-computers).

The `flic` node opens the **host's** Bluetooth controller (`hci0` by default,
selected by its `device_id` parameter) rather than a device mounted into the
container, so that controller must exist and be free before the `real` profile
starts — see
[Real Hardware → Bluetooth adapter](../getting-started/real-hardware.md#bluetooth-adapter-flic-buttons).

MoveIt runs **in-process** inside the Commander (`moveit_py`), not as a separate
`move_group` node — planning is in-process; execution is dispatched to the UR
`controller_manager` action servers.

## Hardware synchronization

The Teensy emits a hardware trigger pulse wired to the FLIR cameras' input line,
so all cameras expose simultaneously; the synchronized driver stamps grouped
frames identically and uses the FrameID chunk as the sync key. Verify sync with:

```bash
ros2 run tabletop_rig system_check
```

## Safety interlock

The Teensy firmware publishes `teensy/sensor` (a `TeensySensor` message) at a
configurable rate. The `TeensyInterface` inside the Commander gates every robot
motion through `safe_to_execute`, which requires the safety conditions to hold
continuously for a configured time and the sensor message to be fresh.

!!! warning "Arm-lock check is off by default"
    By default `safe_to_execute` enforces **only** the safety laser
    (`is_safety_laser_broken`). The arm-lock check (both arms seated in the
    restraints) is gated by the `safe_to_execute.require_arm_locks` parameter in
    `commander.yaml`, which defaults to `false` — so the arm-lock state the
    firmware publishes is **not** enforced unless you set
    `require_arm_locks: true`. Enabling it is a safety-relevant decision; the
    laser-only default preserves the rig's historical behaviour. The mechanism
    that holds / detects the hands (currently a button per hand, not a physical
    lock) is being reworked — see [Known Issues](../known-issues.md).

## Firmware

The Teensy micro-controller firmware lives under
`src/microros/` and is built with PlatformIO (not colcon):

```bash
tt-build microros
```

The Teensy firmware implements the `tabletop_interfaces` services (`SetArmLock`,
`SetReward`, `SetSolenoid`, `SetSmartglass`, `Ping`) and publishes
`TeensySensor`. When changing it, keep the micro-ROS executor handle counts (and
`colcon.meta`) in sync with the number of entities. When in doubt, unplug and
replug, then re-run `tt-env-gen` so Docker re-mounts the device.

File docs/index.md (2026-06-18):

# TableTop

**TableTop** is a ROS 2 platform for controlling Universal Robots UR5e arms in
a monkey electrophysiology research rig. It runs entirely in Docker containers
and uses [MoveIt 2](https://moveit.picknik.ai/) for motion planning.

The system presents physical objects to a subject, measures their responses
(button presses, eye gaze), delivers rewards, and records synchronized sensor
and robot-state data for offline analysis.

## What's here

<div class="grid cards" markdown>

- :material-rocket-launch: **[Getting Started](getting-started/setup.md)** —
  clone, set up the environment, and bring up the containers.
- :material-sitemap: **[Architecture](architecture.md)** — the conceptual
  dependency map: who talks to whom and where to look when something breaks.
- :material-book-open-variant: **[Guide](guide/cli.md)** — CLI tooling,
  configuration, the task system, hardware & safety, and troubleshooting.
- :material-api: **[API Reference](reference/index.md)** — auto-generated
  from the source for `tabletop_py`, `tabletop_rig`, and `tabletop_tasks`.

</div>

## The system at a glance

The platform is layered; each layer only reaches *down*:

```text
┌──────────────────────────────────────────────────────────────────┐
│ EXPERIMENTS   tabletop_tasks: ForagingTask, SmoothPursuitTask, … │
├──────────────────────────────────────────────────────────────────┤
│ ORCHESTRATION tabletop_rig Commander node (aggregates interfaces)│
├──────────────────────────────────────────────────────────────────┤
│ DEVICE NODES  ur driver, teensy, flic, eyelink, flir, optitrack  │
├──────────────────────────────────────────────────────────────────┤
│ ROS PLUMBING  tabletop_interfaces, tabletop_description, moveit  │
├──────────────────────────────────────────────────────────────────┤
│ PURE PYTHON   tabletop_py: gaze ML, flic protocol, utils         │
├──────────────────────────────────────────────────────────────────┤
│ INFRA         bin/ scripts → compose.yaml services → Docker      │
└──────────────────────────────────────────────────────────────────┘
```

Every container shares `network_mode: host` and `ipc: host`, so all ROS nodes
share one DDS domain regardless of which container they run in. See
[Architecture](architecture.md) for the full picture.

!!! note "Conventions"
    Units follow [REP 103](https://www.ros.org/reps/rep-0103.html): meters,
    seconds, radians. Python targets 3.12 and is formatted with `ruff`
    (79-char lines, Google-style docstrings).

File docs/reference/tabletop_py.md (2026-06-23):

# tabletop_py

ROS-independent Python utilities: eye-gaze estimation/tracking, the Flic
button client, and shared helpers. This package never imports ROS — it is
wrapped by `tabletop_rig` nodes and also exposes the `tt-gaze-*` and
`tt-flic-scapy` command-line tools.

## Gaze estimation — `tabletop_py.gaze`

The offline gaze calibration/estimation pipeline (preprocess → train →
predict → visualize) plus EDF parsing and synchronization helpers.

::: tabletop_py.gaze.calibrate
::: tabletop_py.gaze.preprocess
::: tabletop_py.gaze.train
::: tabletop_py.gaze.predict
::: tabletop_py.gaze.visualize
::: tabletop_py.gaze.models
::: tabletop_py.gaze.edf
::: tabletop_py.gaze.utils
::: tabletop_py.gaze.syncer
::: tabletop_py.gaze.sync_aligner
::: tabletop_py.gaze.optitrack_to_sync
::: tabletop_py.gaze.calibrate_camera
::: tabletop_py.gaze.roi_bound_finder

## Flic buttons — `tabletop_py.flic`

Client for the Flic Bluetooth buttons used as the subject's response device.
`scapy_client` is a raw BLE sniffer that reports button presses with minimal
latency. (The older `flicd`-daemon client and the `piano` demo were retired —
see `deprecated/flic-button/`.)

::: tabletop_py.flic.scapy_client

## Shared utilities — `tabletop_py.utils`

::: tabletop_py.utils.common
::: tabletop_py.utils.mesh
::: tabletop_py.utils.dbm_sqlite3

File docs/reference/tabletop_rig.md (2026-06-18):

# tabletop_rig

The core rig-control package: ROS 2 nodes and the layered device interfaces
aggregated by the `Commander`. See [Architecture §5.2](../architecture.md) for
the interface inheritance chain and how the Commander composes them.

## Nodes — `tabletop_rig.nodes`

One ROS 2 node per process. `Commander` is the orchestrator; the rest are
device nodes and mock stand-ins for simulation.

::: tabletop_rig.nodes.base
::: tabletop_rig.nodes.commander
::: tabletop_rig.nodes.eyelink
::: tabletop_rig.nodes.flic
::: tabletop_rig.nodes.system_check
::: tabletop_rig.nodes.mock_teensy
::: tabletop_rig.nodes.mock_dashboard_client
::: tabletop_rig.nodes.mock_robot_state_helper

## Device interfaces — `tabletop_rig.interfaces`

Each interface wraps one subsystem and is owned by the `Commander`.

::: tabletop_rig.interfaces.base
::: tabletop_rig.interfaces.teensy
::: tabletop_rig.interfaces.ur
::: tabletop_rig.interfaces.flic
::: tabletop_rig.interfaces.eyelink
::: tabletop_rig.interfaces.sound

## MoveIt interfaces — `tabletop_rig.interfaces.moveit`

The motion-planning stack: planning scene, plan-and-execute (with fuzzy
trajectory caching), the pick/present/return state machine, and the unified
top-level `MoveItInterface`.

::: tabletop_rig.interfaces.moveit.moveit
::: tabletop_rig.interfaces.moveit.plan_and_execute
::: tabletop_rig.interfaces.moveit.object_manipulation
::: tabletop_rig.interfaces.moveit.requests
::: tabletop_rig.interfaces.moveit.trajectory_cache
::: tabletop_rig.interfaces.moveit.trajectory_cache_kdtree
::: tabletop_rig.interfaces.moveit.trajectory_cache_lmdb

## Async executors & exceptions

::: tabletop_rig.executors
::: tabletop_rig.exceptions

## Utilities — `tabletop_rig.utils`

::: tabletop_rig.utils.ros
::: tabletop_rig.utils.logging
::: tabletop_rig.utils.rosbag

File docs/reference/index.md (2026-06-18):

# API Reference

Auto-generated from the in-source Google-style docstrings via
[mkdocstrings](https://mkdocstrings.github.io/) (static analysis — no ROS or
hardware imports required). Private members (leading underscore) are hidden.

The platform is split into three importable Python packages:

| Package | Role | Depends on |
| --- | --- | --- |
| [`tabletop_py`](tabletop_py.md) | ROS-independent utilities: gaze ML, Flic clients, helpers | — |
| [`tabletop_rig`](tabletop_rig.md) | ROS 2 nodes & device interfaces (incl. in-process MoveIt) | `tabletop_py`, `tabletop_interfaces` |
| [`tabletop_tasks`](tabletop_tasks.md) | Experiment task definitions & trial generators | `tabletop_rig`, `tabletop_py` |

See [Architecture](../architecture.md) for how these fit together at runtime.

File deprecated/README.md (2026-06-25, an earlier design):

# Deprecated / archived components

This directory is an **archive**. Nothing here is built, imported, launched, or
on any runtime code path — `colcon`/`tt-build` ignore it and no active config
references it. Files are kept only so a curious maintainer can see how a
superseded subsystem worked, or revive it if needed.

Generated build artifacts (e.g. the firmware `.pio/` tree, `compile_commands.json`)
and runtime state (daemon logs, databases) were stripped before archiving; only
source-of-reference files remain.

## What moved here, and where it came from

| Archived path | Original location | Why retired |
| --- | --- | --- |
| `flic-button/flicd/` | `docker/flicd/` | `flicd` daemon superseded by the scapy BLE sniffer |
| `flic-button/client.py` | `src/tabletop_py/flic/client.py` | flicd socket client → `scapy_client.py` |
| `flic-button/piano.py` | `src/tabletop_py/flic/piano.py` | demo built on the flicd client |
| `flic-button/flic_node.py` | `tabletop_rig/.../nodes/deprecated/flic.py` | old ROS flic node (flicd-based) |
| `flic-button/tabletop_flic_micro/` | `src/microros/tabletop_flic_micro/` (never existed as a full package; only partial files) | incomplete ESP32 firmware |
| `ursim/entrypoint.sh` | `docker/ursim/entrypoint.sh` | UR simulator support removed |
| `moveit-config/kinematics.yaml` | `tabletop_moveit_config/config/kinematics.yaml` | old single-arm variant |
| `moveit-config/tabletop.xrdf` | `tabletop_moveit_config/xrdf/tabletop.xrdf` | cuMotion/Isaac description, unused |
| `ros-graph/tt-create-graph` | `bin/container/tt-create-graph` | graph tooling no longer maintained |
| `ros-graph/ros_graph_style.yaml` | `config/ros_graph_style.yaml` | styling for `tt-create-graph` |
| `docker/buildkitd.toml` | `docker/buildkitd.toml` | BuildKit GC config, unreferenced |
| `compose-services.yaml` | extracted from `compose.yaml` | removed Compose service definitions |
| `launch/rig.launch.py` | `tabletop_rig/launch/rig.launch.py` | monolithic aggregator superseded by per-service Compose profiles |

## `flic-button/` — the old `flicd`-based Flic button stack

The Flic buttons are the subject's response device. The original stack ran the
proprietary **`flicd`** daemon, which connected to each button over BLE GATT to
read its click-type characteristic. That connection added tens of milliseconds
of latency between the press and the emitted event.

It was replaced by an in-process **scapy BLE sniffer**
(`src/tabletop_py/flic/scapy_client.py`, driven by
`src/ros/tabletop/tabletop_rig/tabletop_rig/nodes/flic.py`). The sniffer opens a
raw HCI socket and reports the button's wake-up advertisement directly, so it
catches the press at the contact-closure edge with no GATT round-trip and no
daemon. The `flic` Compose service simply needs `NET_ADMIN`.

- **`flicd/`** — the `flicd` binary plus its Docker assets (`entrypoint.sh`,
  `healthcheck.sh`, and the binary's `LICENSE`). It ran as the `flicd` Compose
  service (see [`compose-services.yaml`](compose-services.yaml)), exposing a
  socket server on port `5551`.
- **`client.py`** — the asyncio client that spoke the `flicd` socket protocol.
  It was exposed as the `tt-flic-client` entry point (removed from
  `pyproject.toml`). `scapy_client.py` deliberately mirrors its
  `asyncio.Protocol` structure.
- **`piano.py`** — the "FlicPiano" demo: plays musical notes from button presses
  (needs the `mingus` package from the `dev` dependency group). Built on
  `client.py`.
- **`flic_node.py`** — the earlier ROS node that used the flicd client (it lived
  at `tabletop_rig/.../nodes/deprecated/flic.py`). The active
  `tabletop_rig/.../nodes/flic.py` uses `scapy_client` instead.
- **`tabletop_flic_micro/`** — incomplete **ESP32 (Feather ESP32)** firmware that
  read Flic BLE advertisements on-device and published over micro-ROS. It was
  never finished: `resetButtonAds()` connected/disconnected on the main loop and
  could block long enough to stall the executor and drop the micro-ROS agent. It
  had no launch file. It was built with `tt-build microros -t flic_micro` (that
  target was removed from `bin/container/tt-build`).

  Only the files unique to this firmware are kept here — `src/main.cpp` (the
  firmware), `platformio.ini` (ESP32 board/deps), and `colcon.meta`. This is
  therefore **not a buildable PlatformIO package on its own**: to actually build
  it, copy the full package layout from `src/microros/tabletop_teensy/` (its
  `.vscode/`, `include/`, `lib/`, `test/`, `pio_compiledb.py`, `.gitignore`, and
  the `extra_packages/tabletop_interfaces` symlink) and drop these files in,
  then build it the way the Teensy firmware is built.

## `ursim/` — UR5e simulator support

`entrypoint.sh` was the entrypoint for the **`ursim`** Compose service
(`universalrobots/ursim_e-series` image), which ran a virtual UR controller and
teach pendant rendered to the noVNC display. The simulator was dropped:
`robot_mode` now supports only `mock` and `real`, and the `ursim` Compose
profile was removed. The service definition is preserved in
[`compose-services.yaml`](compose-services.yaml).

## `moveit-config/` — MoveIt configs that are no longer loaded

- **`kinematics.yaml`** — the old single-`manipulator:` IK config, with several
  alternative solvers (KDL, cached KDL, `pick_ik`) commented out. The active
  `tabletop_moveit_config/config/kinematics.yaml` uses per-arm
  `left_manipulator` / `right_manipulator` TRAC-IK blocks.
- **`tabletop.xrdf`** — a single-arm cuRobo/Isaac **XRDF** robot description for
  the `isaac_ros_cumotion` planning pipeline (also retired). The package's whole
  `xrdf/` directory was removed, including from its CMake `install(DIRECTORY …)`.

## `ros-graph/` — ROS graph generation tooling

- **`tt-create-graph`** wrapped `ros2_graph` python package (now removed from
  `pyproject.toml`) to render the live ROS 2 node/topic graph to `graph.md`
  (run after `tt-launch`, while nodes are up).
  Note: it `source`s `../../setup.bash` and `../utils.sh` relative to its old
  home `bin/container/`; to revive it, restore it there so those paths resolve.
- **`ros_graph_style.yaml`** was the graph styling config it consumed.

## `docker/buildkitd.toml`

BuildKit daemon configuration (garbage-collection policies and cache-size
limits). No longer referenced by the build setup.

## `compose-services.yaml`

The Compose **service definitions** removed from the top-level `compose.yaml`,
kept verbatim under a `deprecated` profile for reference (no user profile starts
them):

- **`ursim`** — the UR5e simulator (see above).
- **`flicd`** — the `flicd` daemon bridge (see above).
- **`flir-no-sync`** — the unsynchronized FLIR camera driver (one device per
  `$FLIR_DEV_*`), superseded by the hardware-synchronized `flir` service. (The
  `flir_no_sync` *launch target* still exists and is used by `tt-flir-reset`; it
  is only the standalone Compose service that was removed.)

## `launch/rig.launch.py` — monolithic rig aggregator

`rig.launch.py` was a single launch file that conditionally included every rig
subsystem (commander, dual UR driver, Teensy, Flic, Eyelink, FLIR, OptiTrack,
RViz, rosbag) behind per-subsystem `*_launch` boolean arguments. It was the
target of `tt-launch rig` and was included by `tasks.launch.py`.

It became obsolete once each subsystem was given its own docker-compose service
running its own dedicated launch file: there is no longer a single process that
needs to aggregate all of them. The `tt-launch rig` target has been removed.

`tasks.launch.py` now includes `commander.launch.py` and `rosbag.launch.py`
directly instead of going through this aggregator.

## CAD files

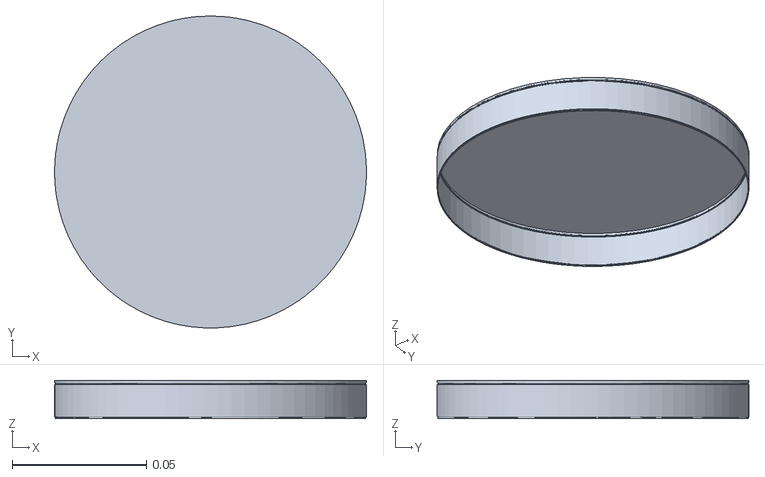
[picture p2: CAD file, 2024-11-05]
virtual_tabletop/universal_robots_ur5e/assets/base_0.obj
0.116 x 0.116 x 0.0142

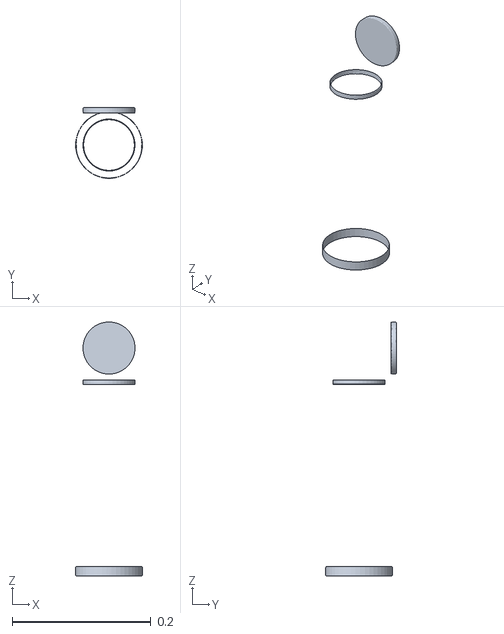
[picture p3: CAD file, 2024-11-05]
virtual_tabletop/universal_robots_ur5e/assets/forearm_2.obj
0.0959 x 0.102 x 0.366

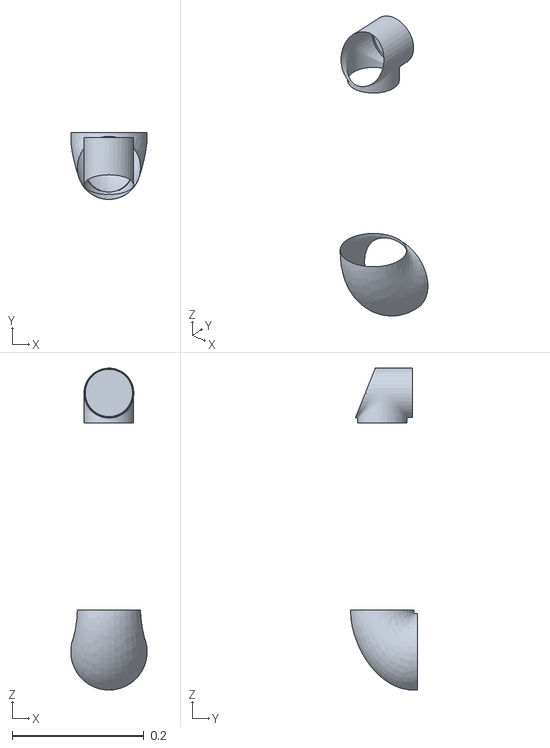
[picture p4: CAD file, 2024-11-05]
virtual_tabletop/universal_robots_ur5e/assets/forearm_3.obj
0.116 x 0.102 x 0.488

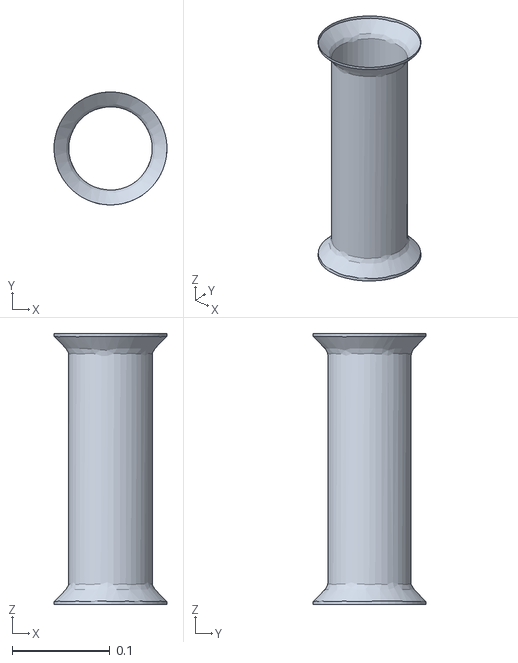
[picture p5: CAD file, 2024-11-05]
virtual_tabletop/universal_robots_ur5e/assets/upperarm_0.obj
0.116 x 0.116 x 0.278

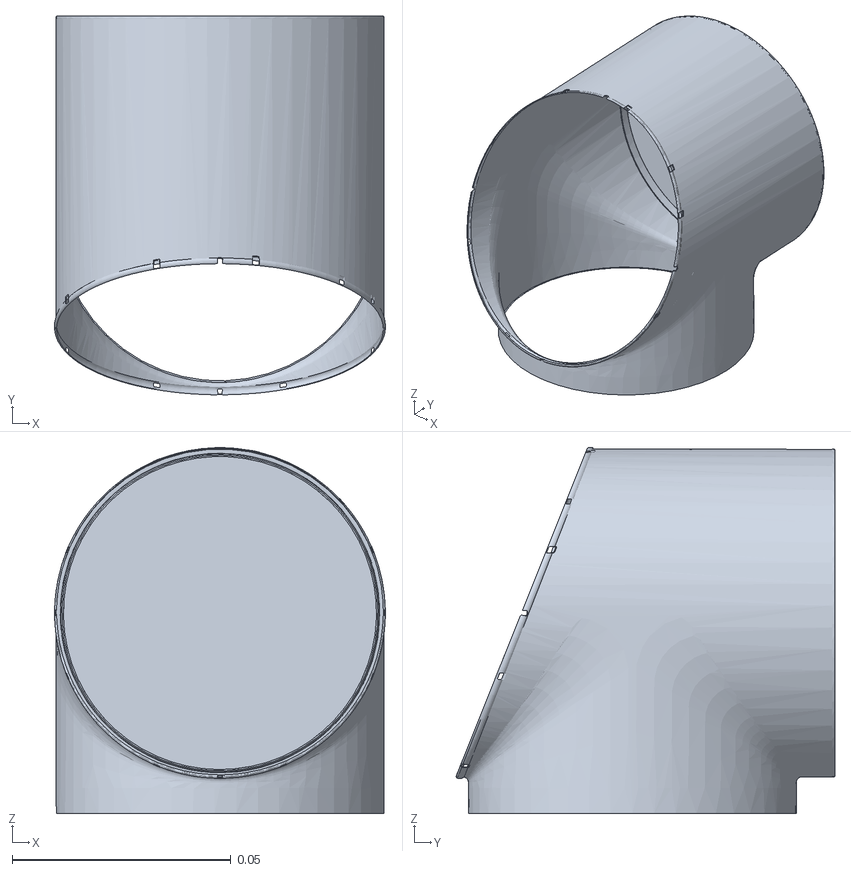
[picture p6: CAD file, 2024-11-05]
virtual_tabletop/universal_robots_ur5e/assets/wrist2_2.obj
0.0757 x 0.0866 x 0.0837

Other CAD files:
src/ros/tabletop/tabletop_description/meshes/visual/eef.stl
src/ros/tabletop/tabletop_rig/meshes/objects/big_object_14.stl
src/ros/tabletop/tabletop_rig/meshes/rig/reset_station.step
virtual_tabletop/monkey_arm/bones/clavicle.stl
src/ros/tabletop/tabletop_rig/meshes/objects/big_object_11.stl
src/ros/tabletop/tabletop_rig/meshes/rig/rig.step
virtual_tabletop/monkey_arm/bones/scapula.stl
src/ros/tabletop/tabletop_rig/meshes/objects/big_object_25.stl
virtual_tabletop/monkey_arm/bones/radius.stl
src/ros/tabletop/tabletop_rig/meshes/objects/big_object_30.stl
virtual_tabletop/monkey_arm/bones/hand.stl
src/ros/tabletop/tabletop_rig/meshes/objects/big_object_15.stl
virtual_tabletop/monkey_arm/bones/humerus.stl
src/ros/tabletop/tabletop_rig/meshes/objects/big_object.stl
src/ros/tabletop/tabletop_rig/meshes/objects/big_object_0.stl
src/ros/tabletop/tabletop_rig/meshes/objects/big_object_1.stl
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

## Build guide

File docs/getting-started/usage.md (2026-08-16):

# Usage

## Building

All builds happen inside the container; the `tt-*` wrappers handle that for you.
`tt-build` takes a required component — `colcon`, `microros`, or `foxglove`:

```bash
tt-compose --profile='*' pull     # pull the prebuilt Docker images from Docker Hub
tt-build colcon --all             # full workspace incl. external modules (moveit2) — run this first
tt-build colcon                   # tabletop packages only (most common, after the first build)
tt-build colcon --clean-tabletop  # clean rebuild of tabletop packages
tt-build colcon -p tabletop_rig   # one package + its dependencies
tt-build microros                 # Teensy firmware (PlatformIO)
tt-build foxglove                 # Foxglove MoveIt plugin (.foxe -> $TABLETOP_DIR)
```

Run `tt-build colcon --all` the **first** time so the external modules (moveit2,
etc.) are built too. After that you can drop `--all` and just run
`tt-build colcon`, as long as you are only changing the tabletop packages.

See [CLI & Tooling](../guide/cli.md) for the full option list.

## Starting containers (profiles)

Services are grouped by Compose **profiles**. Bring up a whole session with
`tt-compose --profile=<name> up`:

| Profile | Brings up | Use case |
| --- | --- | --- |
| `sim` | mock UR, teensy-sim, flic-sim, eyelink-sim, rviz, foxglove, novnc | development with mock hardware |
| `real` | ur, teensy, flic, eyelink, optitrack, flir, rviz, foxglove, novnc | real hardware |

```bash
# Simulation (most common for development)
tt-compose --profile=sim up [--detach]

# Real hardware
tt-compose --profile=real up

# Status / logs / teardown
tt-compose ps
tt-compose --profile=sim logs -f [<service>]
tt-compose --profile=sim down
```

!!! tip "Pre-flight check before `--profile=real`"
    The `real` profile expects its host devices to already be present — the
    containers do not create them. A quick check before bringing the rig up
    saves a round of confusing container failures:

    ```bash
    ls /sys/class/bluetooth/   # hci0 — Bluetooth adapter for the flic node
    ls /dev/flir/              # one symlink per FLIR camera
    ls /dev/ttyACM*            # Teensy serial device (must match TEENSY_DEV in .env)
    ```

    A missing `hci0` is the common one: the Bluetooth hardware can be present
    while the kernel drivers were never loaded, and the `flic` container then
    fails with `No such device` and no `/flic` node ever joins the ROS graph.
    See
    [Real Hardware → Bluetooth adapter](real-hardware.md#bluetooth-adapter-flic-buttons)
    for the fix, and re-run `tt-env-gen` if a camera or the Teensy is missing.

Open the noVNC desktop (RViz, UR sim teach pendant) at
<http://localhost:8080/vnc.html> (replacing 8080 with
whatever port is set by `NOVNC_PORT` in `.env`) or
connect Foxglove to `ws://localhost:8765`.

## Foxglove visualization

The `foxglove` service exposes a [Foxglove](https://foxglove.dev/) WebSocket
bridge at `ws://localhost:8765`. Open the Foxglove app (web or desktop), choose
**Open connection → Foxglove WebSocket**, and enter that URL (replace the port
if you changed `FOXGLOVE_PORT` in `setup.bash`). See the
[Foxglove documentation](https://docs.foxglove.dev/docs) for the full
visualization workflow.

### Layout configs

Foxglove lets you save and restore panel arrangements as **layout** JSON files.
To import a layout:

1. Open Foxglove (web or desktop) and connect to the WebSocket bridge.
2. Click the **layout** icon (top-left panel selector) → **Import from file…**
3. Select a `.json` layout file and confirm.

Two sample layout JSON files have been provided in the `share/foxglove/`
directory: `planning-scene-layout.json` and `cameras-layout.json`.
The former includes a panel for the planning scene as well as six
small panels for each Flir camera feed. The latter has the same
six cameras but also a plotting panel to verify that the Teensy
sync pulse is being seen on the camera meta-data topics.

### MoveIt converter plugin (`.foxe`)

To visualize MoveIt planning scenes, install the bundled Foxglove extension.
Build and package it with:

```bash
tt-build foxglove                            # writes to $TABLETOP_DIR
tt-build foxglove -o ~/plugins               # write into a directory (keeps the packaged name)
tt-build foxglove -o ~/plugins/moveit.foxe   # write to a specific filename
```

This packages the `src/foxglove_moveit_msg_converter` extension and writes the
resulting `.foxe` file to `$TABLETOP_DIR` (the repository root) by default, or to
the `-o/--output` path — a directory (the plugin keeps its packaged name) or a
path ending in `.foxe` (the plugin is renamed to it). Install it into the
Foxglove app by opening the extensions settings and adding the local `.foxe`; see
the
[Foxglove extensions guide](https://docs.foxglove.dev/docs/visualization/extensions/introduction)
for the exact steps for your Foxglove version.

!!! warning "Keep Foxglove open and focused when a task starts"
    The MoveIt planning scene is pushed as a burst of messages at task
    initialisation.  If Foxglove is **not open and focused** (e.g. the browser
    tab is backgrounded or the app is minimised) when the task starts, it will
    miss those planning-scene updates and the 3-D scene will appear empty or
    incomplete.  Re-open the connection **before** launching a task, or trigger
    a scene refresh after connecting.

## Dev Container (VS Code)

Install the **Dev Containers** extension, run `tt-env-gen`, open the folder, and
choose **Reopen in Container**. Inside, `tt-build` and `tt-launch` work directly.
To open a shell in a non-dev service instead, use `tt-attach <service>` (see
[CLI & Tooling](../guide/cli.md)).

!!! note "GPU access in the Dev Container"
    The Dev Container runs under `$COMMANDER_RUNTIME`, which defaults to `runc`
    (CPU-only). If you need the GPU inside it, set `COMMANDER_RUNTIME=nvidia`
    in `.env`, re-run `tt-env-gen`, and rebuild/reopen the container — see
    [Setup → GPU](setup.md#gpu-nvidia-container-runtime).

!!! note
    Source changes for nodes running in *other* containers require restarting
    or rebuilding those containers to take effect.

## Running a task

Tasks are the behavioral experiments. `tt-launch` runs inside a container. The
recommended way is to open a shell in the `commander` service with `tt-attach`
(or use the Dev Container) and run `tt-launch` from there:

```bash
tt-attach commander       # open a shell in a fresh commander container, then:
tt-launch tasks                                              # default foraging task, mock robot
tt-launch tasks task:=foraging_ordered robot_mode:=mock     # specific task + robot mode
tt-launch tasks task:=smooth_pursuit_random robot_mode:=real
```

Alternatively, run a task as a one-shot from the host — this spins up a temporary
`commander` container and tears it down when the task exits:

```bash
tt-compose run --rm commander tt-launch tasks task:=foraging_ordered robot_mode:=mock
```

`Ctrl-C` stops a running task. The `task` argument is a config filename (without
`.yaml`) from `tabletop_tasks/config/`; `robot_mode` is `mock` or `real`. See
[Tasks & Experiments](../guide/tasks.md) for the available tasks and how to
configure them.

Pass `rosbag:=true` to also record the session to an MCAP bag (topics from
`rosbag.yaml`); recording is off by default. See below for turning a recorded
bag into analysis-ready files.

## Converting recorded bags

Sessions are recorded as MCAP rosbags. Use **`tabletop_unbag`** (`unbag`) to turn
a bag into per-topic CSVs and decoded image files: nested fields become
dot-separated columns (`pose.position.x`), sequences become bracket-indexed
columns (`name[0]`), and image topics are decoded to image files.

`unbag` is a standalone C++ exporter with no Python/pandas/rclpy runtime
dependency. It is multithreaded, streams the bag (bounded memory, so it handles
very large camera-heavy bags), and is resumable (an interrupted run leaves valid
partial output and picks up where it left off). It is built by the normal
`tt-build colcon`:

```bash
# Export everything into <parent of BAG_DIR>/unbag/
ros2 run tabletop_unbag unbag /path/to/session/bag

# Choose the output directory; only CSV (skip image topics)
ros2 run tabletop_unbag unbag BAG_DIR -o /path/to/out --handlers csv

# Restrict to some topics; save every image as lossless PNG
ros2 run tabletop_unbag unbag BAG_DIR --topics /joint_states /eyelink/sample
ros2 run tabletop_unbag unbag BAG_DIR --handlers image --image-format png

# Re-run from scratch instead of resuming
ros2 run tabletop_unbag unbag BAG_DIR --overwrite
```

CSV output is byte-for-byte identical to the legacy Python converter, with one
intentional difference: fixed-size primitive arrays (e.g. `CameraInfo.k`) are
expanded to indexed columns (`k[0]..k[8]`). The full flag set (handler
selection, `--jobs`, `--csv-batch-size`, `--image-encoding`, resume/overwrite
semantics) is documented in `src/ros/tabletop/tabletop_unbag/README.md`.

!!! note "Legacy Python converter"
    `tabletop_unbag` was ported from a Python converter
    (`tabletop_rig.utils.rosbag`, `rosbag_to_csv`). That converter's `tt-launch`
    target has been removed and it is slated for retirement — prefer `unbag`. It
    currently survives only as the `ros2 run tabletop_rig rosbag_to_csv` entry
    point and the import used by the gaze-calibration scripts (which will move to
    `tabletop_unbag`; see `docs/fix-plan.md`).

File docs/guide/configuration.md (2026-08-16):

# Configuration

Configuration enters the system at three levels: the Docker **environment**
(`.env`), ROS **launch arguments**, and ROS **parameter files** (YAML). This
page maps each config file to what consumes it; see
[Architecture §4](../architecture.md) for the full parameter-flow diagram.

## Environment (`.env`)

`tt-env-gen` generates `.env` from `.env.example`. It **validates** required
variables and **auto-detects** a few:

- **Auto-detected:** FLIR cameras (`FLIR_DEV_0..N` from `/dev/flir/*` udev
  symlinks) and the PulseAudio socket (`PULSE_*`).
- **Set by you:** serial device paths (currently only `TEENSY_DEV`) and the
  container runtime (`COMMANDER_RUNTIME`, plus `CUDA_VERSION`) are **not**
  auto-detected — edit them to match your hardware. Regenerate with
  `tt-env-gen` (or `tt-env-gen --clean` to start fresh) after any hardware
  change.
- **Derived:** `tt-env-gen` computes `UV_EXTRA` and the `NVIDIA_*` variables
  from `COMMANDER_RUNTIME`, so re-run it after editing that value.

`compose.yaml` reads these for device mounts, runtimes, and volumes.

### Required variables (set in `.env.example`)

| Variable | Description | Default |
| --- | --- | --- |
| `NOVNC_DISPLAY` | X11 display number for the noVNC server | `:20.0` |
| `NOVNC_WIDTH` / `NOVNC_HEIGHT` | X11 display width / height (pixels) | `1920` / `1080` |
| `NOVNC_PORT` | Localhost port serving the noVNC interface | `8080` |
| `COMMANDER_RUNTIME` | Container runtime for the `commander` and `dev` services — `nvidia` for GPU access, `runc` for CPU only | `runc` |
| `CUDA_VERSION` | CUDA version suffix for PyTorch (must match your GPU driver); required only when `COMMANDER_RUNTIME=nvidia` | `130` |
| `BIND_CONSISTENCY` | Docker bind-mount consistency mode (macOS/Windows only, ignored on Linux) | `cached` |
| `TEENSY_DEV` | Serial device path for the Teensy micro-controller | `/dev/ttyACM0` |
| `FLIR_MAX_DEVS` | Maximum number of FLIR cameras mapped into containers | `6` |

`tt-env-gen` validates that these are present (it does **not** auto-detect
serial device paths or the container runtime — set `TEENSY_DEV` and
`COMMANDER_RUNTIME` to match your hardware).

### Auto-generated variables (by `tt-env-gen`)

`tt-env-gen` automatically detects and configures:

- **FLIR cameras** — detects `/dev/flir/*` udev symlinks and maps them to
  `FLIR_DEV_0..N` (up to `FLIR_MAX_DEVS`).
- **PulseAudio** — detects the PulseAudio socket and configures the `PULSE_*`
  mount variables for audio passthrough (falls back to `/dev/null` if not
  found).
- **GPU variables** — derived from the `COMMANDER_RUNTIME` you set (see below),
  not from probing the host: `UV_EXTRA` and the `NVIDIA_*` variables.

### GPU access (NVIDIA container runtime)

GPU access is **opt-in**: the runtime is not auto-detected, so a fresh `.env`
runs the `commander` and `dev` containers on plain `runc` with CPU-only PyTorch
wheels until you say otherwise. To enable it:

1. Install the [NVIDIA driver](https://www.nvidia.com/en-us/drivers/) and the
   [NVIDIA Container Toolkit](https://docs.nvidia.com/datacenter/cloud-native/container-toolkit/install-guide.html)
   on the host, so Docker has an `nvidia` runtime to use.
2. Edit `.env` (**not** `.env.example`):

    ```bash
    COMMANDER_RUNTIME=nvidia
    CUDA_VERSION=130          # match your driver; see pyproject.toml for the
                              # available cu* extras (126, 128, 130)
    ```

3. Re-run `tt-env-gen` so the derived variables are refreshed, then recreate the
   containers:

    ```bash
    tt-env-gen
    tt-compose --profile=<sim|real> up --force-recreate
    ```

`tt-env-gen` accepts only `nvidia` or `runc` and errors out on anything else
(or on `nvidia` with an empty `CUDA_VERSION`). Setting `nvidia` **without** the
NVIDIA Container Toolkit installed leaves `.env` valid but makes Docker fail to
start the `commander`/`dev` containers with an unknown-runtime error — see
[Troubleshooting](troubleshooting.md#environment-configuration).

| `COMMANDER_RUNTIME` | `UV_EXTRA` | `NVIDIA_VISIBLE_DEVICES` / `NVIDIA_DRIVER_CAPABILITIES` |
| --- | --- | --- |
| `nvidia` | `--extra cu$CUDA_VERSION` | `all` / `all` |
| `runc` | `--extra cpu` | empty / empty |

!!! warning "Upgrading from an autodetecting `.env`"
    Earlier versions of `tt-env-gen` probed `nvidia-smi` and wrote
    `COMMANDER_RUNTIME` into the *Dynamic Configuration* block at the bottom of
    `.env`. If your `.env` predates this change, the variable is still down
    there holding whatever autodetection last decided. Set the value you want in
    that file (or run `tt-env-gen --clean` to regenerate from the current
    `.env.example` — this discards your other `.env` edits) and re-run
    `tt-env-gen`.

## Parameter files (config → consumer)

| Config | Consumed by | Drives |
| --- | --- | --- |
| `tabletop_rig/config/commander.yaml` | `commander.launch.py` → Commander | all interface parameters |
| `tabletop_rig/config/flir_synchronized.yaml` | `flir_synchronized.launch.py` | camera serials, trigger/chunk settings, poses |
| `tabletop_rig/config/dual_controllers.yaml` | `dual_ur.launch.py` → controller_manager | left/right controller definitions |
| `tabletop_rig/config/optitrack.yaml` | `optitrack.launch.py` | server address, ports, QoS |
| `tabletop_rig/config/rosbag.yaml` | `rosbag.launch.py` | recorded topics/services, bag size |
| `tabletop_rig/config/object_reset/*.yaml` | Commander `reset_object` | reset-motion strategies (drawer/spin) |
| `tabletop_tasks/config/<task>.yaml` | `tasks.launch.py` → `run_tasks` | task class + kwargs + trial generator |
| `tabletop_description/config/*_calibration.yaml` | `dual_rsp.launch.py` | per-arm UR kinematics |
| `tabletop_moveit_config/config/*.yaml` | `commander.launch.py`, `moveit.launch.py` | planners, limits, controllers |

Every config file is now commented inline; open the file to see per-parameter
documentation.

!!! tip "FLIR GenICam node reference"
    The `blackfly_s.yaml` and `flir_synchronized.yaml` config files map ROS
    parameter names to GenICam "node" paths on the camera (e.g.
    `AcquisitionControl/TriggerMode`). The authoritative list of nodes for the
    **BFS-U3-23S3** model used in this rig is the
    [FLIR BFS-U3-23S3 GenICam node reference](https://softwareservices.flir.com/BFS-U3-23S3/latest/Model/public/index.html).
    Node names, allowed values, and availability may differ for other Blackfly S
    variants — consult the corresponding FLIR model page for other cameras.

For a detailed breakdown of every parameter accepted by the `Commander` node and
its interfaces, see [Node & Interface Parameters](parameters.md).

## The common / override pattern

`commander.yaml` is the master parameter file for the `Commander` node. Its
interface sections resolve via `BaseInterface.param(name)`, which looks up
`<iface_prefix>.<name>` and falls back to `common_<kind>_interface.<name>`. For
example, `left_ur_interface.namespace` overrides the shared
`common_ur_interface.*`. The same common/override idiom appears in
`flir_synchronized.yaml` (`camera_params_common` vs. `camera_params`) and task
configs.

At launch, `commander.launch.py` merges `commander.yaml` with a per-session
`/tmp/commander_overrides.yaml` (e.g. `robot_mode`, `initial_object`).

!!! tip "MoveIt configs"
    Files under `tabletop_moveit_config/config/` (OMPL, Pilz, CHOMP, STOMP,
    kinematics, joint limits, controllers) follow standard MoveIt conventions
    and are auto-discovered by `MoveItConfigsBuilder`. Each carries a header
    comment describing its role; refer to the
    [MoveIt docs](https://moveit.picknik.ai/) for the individual parameters.

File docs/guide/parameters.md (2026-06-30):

# Node & Interface Parameters

This page summarises the main ROS 2 parameters accepted by the `Commander` node
and its interfaces.  The canonical, always-up-to-date source is the config file
itself:

```
src/ros/tabletop/tabletop_rig/config/commander.yaml
```

Every parameter in that file carries an inline comment.  The sections below are
a first-pass overview, grouped by node/interface; refer to the YAML for the
exact types, defaults, and caveats.

## Common / override pattern

`commander.yaml` is loaded by `commander.launch.py` and merged at runtime with a
per-session `/tmp/commander_overrides.yaml` (populated by `tt-launch` from
launch arguments such as `robot_mode`).

Lookups use `BaseInterface.param(name)`: the per-interface key takes precedence,
then falls back to the corresponding `common_*` section (dict values are
deep-merged).  For example, `left_ur_interface.namespace` overrides
`common_ur_interface.namespace`.

---

## Commander (nodes/commander.py)

| Parameter | Description |
| --- | --- |
| `simulate` | When `true` (set from `robot_mode:=mock`), skips the post-grasp effort check and relaxes certain UR mode assertions.  Consumed only by the per-arm manipulation stack. |
| `shutdown_timeout` | Maximum seconds to wait for all interfaces to shut down cleanly (default `3.0`). |
| `robot_interface_names` | Maps logical manipulator names to the three per-arm interface instance names (`ur_interface_name`, `manipulation_interface_name`, `manipulation_context_interface_name`). |
| `smooth_pursuit.reward_duration` | Duration (s) of each individual reward pulse during smooth-pursuit. |
| `smooth_pursuit.reward_interval` | Minimum interval (s) between consecutive reward pulses. |
| `smooth_pursuit.reward_threshold_ratio` | Minimum ratio of "pursing" feedback messages needed to activate reward. |
| `flic.bd_addrs` | Map of `object_id` → Bluetooth MAC address for each Flic 2 button. |

---

## SoundInterface (interfaces/sound.py)

| Parameter | Description |
| --- | --- |
| `enable` | Set `false` to silence all audio output. |
| `soundfont_path` | Absolute path to a SoundFont `.sf2` file. |
| `instrument` | General MIDI instrument number (0–127); default `62` (Synth Brass 1). |
| `default_note.{name,octave,velocity,channel}` | Note played by `SoundInterface.play()` when no note is specified. |
| `default_duration` | Default playback duration (s) for `SoundInterface.play()`. |

---

## TeensyInterface (interfaces/teensy.py)

| Parameter | Description |
| --- | --- |
| `safe_to_execute.required_time` | Seconds the safety conditions must be continuously met before `safe_to_execute` returns `True`. |
| `safe_to_execute.max_sensor_delay` | Maximum age (s) of the last `TeensySensor` message before the sensor is considered stale and `safe_to_execute` returns `False`. |
| `safe_to_execute.require_arm_locks` | When `true`, motion additionally requires **both** arm locks engaged, not just the safety laser. Default `false` (laser-only) preserves the rig's historical behaviour. See [Hardware & Safety](hardware.md#safety-interlock). |
| `spin_period` | Poll interval (s) in `lock_arms_and_wait` / `start_reward_and_wait` busy-wait loops. |
| `sensor_delay_warn_threshold` | Log a warning when ROS receive latency of a `TeensySensor` message exceeds this value (s). |
| `sensor_ahead_threshold` | Mark the Teensy clock out of sync if it runs ahead of host time by more than this value (s). |

---

## URInterface (interfaces/ur.py)

Shared defaults live in `common_ur_interface`; per-arm sections
(`left_ur_interface`, `right_ur_interface`) override individual keys.

| Parameter | Description |
| --- | --- |
| `namespace` | ROS topic/node namespace prefix for this arm's UR driver nodes (`left` / `right`). |
| `installation` | UR controller installation file name loaded on the teach pendant. |
| `program` | UR controller program file name to load and play for `external_control`. |
| `max_reset_attempts` | Maximum total recovery attempts before giving up. |
| `reset_retry_delay` | Seconds between consecutive reset attempts. |
| `safety_restart_enable` | If `true`, automatically restarts the safety controller on `VIOLATION`/`FAULT`; if `false`, waits for operator intervention. |
| `safety_restart_delay` | Seconds to wait before calling `restart_safety` (gives the operator a window to abort). |
| `safety_restart_timeout` | Seconds to wait for the robot to complete a safety restart. |
| `check_remote_control_delay` | Seconds between polling for remote-control mode to become active. |
| `check_safety_mode_delay` | Seconds between polling for safe safety mode after a protective stop. |
| `post_reset_delay` | Seconds to wait after a successful reset before returning control. |

---

## ObjectManipulationInterface / PlanAndExecuteInterface

Shared defaults live in `common_manipulation_interface`; per-arm sections
(`left_manipulation_interface`, `right_manipulation_interface`) override them.

### Planning

| Parameter | Description |
| --- | --- |
| `planning.fast_pipeline` | Primary planning pipeline (e.g. `ptp` for Pilz point-to-point). |
| `planning.fallback_pipeline` | Fallback pipeline when the fast path fails (e.g. `aps_rrt_star`). |
| `planning.default_max_attempts` | Default maximum planning attempts per request. |
| `planning.default_exp_backoff_factor` | Exponential backoff multiplier applied to planning timeouts on retry. |
| `planning.max_backoff_time` | Cap on the backoff delay (s) between retries. |
| `planning.default_pose_link` | Link used to evaluate end-effector poses (per-arm; e.g. `left_eef`). |

### Trajectory cache

| Parameter | Description |
| --- | --- |
| `trajectory_cache.base_dir` | Root directory for cached trajectories. |
| `trajectory_cache.use_cached_trajectories` | If `false`, always plans from scratch. |
| `trajectory_cache.freeze_cache` | If `true`, reads from cache but never writes new entries. |
| `trajectory_cache.backend` | Cache backend: `lmdb` (persistent), `kdtree`, `dict`, or `linear`. |
| `trajectory_cache.kwargs` | Backend-specific keyword arguments (e.g. `position_tolerance`, `orientation_tolerance`, `sort_by`). |

### Execution

| Parameter | Description |
| --- | --- |
| `execution.allowed_duration_scaling` | Multiplier on nominal trajectory duration for the execution timeout window. |
| `execution.allowed_duration_margin` | Additional seconds added to the scaled duration window. |
| `execution.allowed_start_tolerance` | Maximum joint-position error (rad) between current state and trajectory start before execution is blocked. |
| `execution.allowed_end_tolerance` | Maximum joint-position error (rad) at the end of execution before the result is considered a failure. |
| `execution.joint_trajectory_controller` | ROS 2 controller action name used to send trajectories (per-arm). |

### Object attachment / manipulation

| Parameter | Description |
| --- | --- |
| `test_object_attached.enable` | If `false`, skip the post-grasp effort check. |
| `test_object_attached.joint_name` | Joint whose effort is sampled for attachment detection. |
| `test_object_attached.effort_threshold` | Effort threshold (Nm) compared with `greater_than` to confirm attachment. |
| `detach_velocity_scaling_factor` | Velocity scaling (0–1) applied when detaching an object from its mount. |
| `skip_idle_on_return` | If `true`, skip moving to the idle pose when returning from the presented state. |
| `skip_fetched_on_fetch` | If `true`, skip the fetched pose when the object is already beyond the pre-fetch waypoint. |
| `persistent_state_path` | File path where the arm's persistent manipulation state is pickled across sessions. |
| `attach_link` | Robot link to which the grasped object collision mesh is attached. |
| `touch_links` | Links allowed to touch the attached object without collision error. |
| `mount_collision_ids` | Collision IDs of the physical rig mount, excluded from collision checking during manipulation. |
| `manipulation_state_goals` | Named waypoint goals for each stage of the fetch/present/return state machine (type: `named_target_state` or `offset`). |
| `reset_config_map` | Per-object reset YAML paths; `null` means the object cannot be reset via `reset_object`. |

---

## ManipulationContextManager (nodes/commander.py)

Shared defaults live in `common_manipulation_context_interface`.

| Parameter | Description |
| --- | --- |
| `interruptions.max_attempts` | Maximum times a manipulation action is retried after an interruption (e.g. safety stop) before raising. |
| `reset.max_attempts` | Maximum times the reset coroutine is retried before giving up. |

---

## MoveItInterface (interfaces/moveit/moveit.py)

| Parameter | Description |
| --- | --- |
| `current_state_wait_time` | Seconds to wait for the planning scene monitor to report a fresh robot state. |
| `link_padding` | Per-link collision padding (m) added to the robot's collision geometry. |
| `exclusive_regions` | Named collision regions that only one arm may occupy at a time; `collision_ids` lists the wall IDs that gate access. |
| `planning_scene.cache_dir` | Directory where the serialised scene and collision matrix are cached. |
| `planning_scene.use_saved_scene` | If `true`, load scene from cache when the config+mesh hash matches. |
| `planning_scene.rig.primitives` | Static box/plane collision objects for the physical rig structure. |
| `planning_scene.rig.meshes` | Static mesh collision objects (rig body, reset stations). |
| `planning_scene.grid_objects` | Dynamic experiment objects placed on the 10×3 presentation grid. |

---

## Other config files

The table in [Configuration](configuration.md#parameter-files-config--consumer)
lists the remaining config files.  Key ones:

- `tabletop_rig/config/flir_synchronized.yaml` — camera list, serial numbers,
  trigger/chunk settings, exposure controller, and camera poses.  See also the
  [FLIR GenICam node reference](configuration.md#parameter-files-config--consumer)
  tip in that page for the BFS-U3-23S3 node reference link.
- `tabletop_rig/config/blackfly_s.yaml` — mapping from ROS parameter names to
  GenICam node paths, shared by the unsynchronised FLIR driver.
- `tabletop_tasks/config/<task>.yaml` — task class, kwargs, and trial generator.
  See [Tasks](tasks.md).
- `tabletop_moveit_config/config/*.yaml` — MoveIt planners, limits, and
  controllers.  Follow standard MoveIt conventions; see the
  [MoveIt docs](https://moveit.picknik.ai/).

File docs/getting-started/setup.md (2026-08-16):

# Setup

TableTop runs in Docker, so the only hard host requirement is Docker itself.
GPU, audio, and firmware tooling are optional. For the full real-hardware
walkthrough (the TableTop network, URCaps, remote control), see
[Real Hardware Setup](real-hardware.md).

## Requirements

| Requirement | Needed for | Install |
| --- | --- | --- |
| [Docker](https://docs.docker.com/engine/install/) | everything | official docs — complete the install **and** [post-install steps](https://docs.docker.com/engine/install/linux-postinstall/) (see the note below) |
| [Bash](https://www.gnu.org/software/bash/) (recent, ≥ 4) | the `tt-*` scripts | preinstalled on Linux; Can be [installed via `brew`](https://formulae.brew.sh/formula/bash) on macOS, which ships with version 3.2 by default |
| [uv](https://docs.astral.sh/uv/) | host Python env + `tt-env-gen` | official docs |
| [git-lfs](https://git-lfs.com/) | large file assets stored in the repo | `sudo apt install git-lfs` (Ubuntu) or `brew install git-lfs` (macOS), then `git lfs install` |
| [jq](https://jqlang.github.io/jq/) | some `tt-*` shell scripts | `sudo apt install jq` (Ubuntu) or `brew install jq` (macOS) |
| [VS Code](https://code.visualstudio.com/) | Dev Container development | optional |
| [NVIDIA driver](https://www.nvidia.com/en-us/drivers/) | GPU in containers | optional; install the driver for your distro + GPU per your vendor/distro instructions |
| [NVIDIA Container Toolkit](https://docs.nvidia.com/datacenter/cloud-native/container-toolkit/install-guide.html) | GPU in containers | optional; needs the NVIDIA driver above, **and** `COMMANDER_RUNTIME=nvidia` in your `.env` — see [GPU](#gpu-nvidia-container-runtime) |
| PipeWire/PulseAudio | reward sounds | see [Audio](#audio-reward-sounds) |
| CPU governor software (e.g. [cpufrequtils](https://manpages.ubuntu.com/manpages/noble/man1/cpufreq-info.1.html)) | disabling CPU speed scaling for real-time control (real hardware) | optional; any mechanism that pins the `performance` governor works — `cpufrequtils` is just one example. See [Real Hardware Setup](real-hardware.md#cpu-governor-real-time-control) |

!!! note "Real hardware tested on Ubuntu 24.04"
    The full real-hardware stack has only been tested with a host running
    **Ubuntu 24.04**. The host-configuration commands in
    [Real Hardware Setup](real-hardware.md) are Ubuntu 24.04 examples; adapt
    them for other distributions.

!!! tip "Apple Silicon"
    Enable **Use Rosetta for x86/amd64 emulation** in Docker Desktop to run the
    x86 container images.

!!! important "Docker permissions and Docker Hub login"
    These are part of Docker's standard installation and
    [post-installation](https://docs.docker.com/engine/install/linux-postinstall/)
    steps — if you already completed those when installing Docker, you can skip
    ahead. Without them the steps below will fail:

    - **Add your user to the `docker` group** so the `tt-*` and `docker`
      commands work without `sudo`:

        ```bash
        sudo usermod -aG docker $USER
        ```

        Group-membership changes only take effect after you **log out and log
        back in**.  On some systems a full **reboot** may be required — a
        simple log-out/log-in is not always sufficient.  Confirm with
        `groups`: the output should include `docker`.

    - **Log in to Docker Hub** so you can pull the prebuilt TableTop images:

        ```bash
        docker login
        ```

## Minimal install

```bash
# 1. Clone and pull submodules
git clone --recurse-submodules https://github.com/jazlab/tabletop.git
cd tabletop

# If you forgot to use `--recurse-submodules` when cloning,
# you can use the following command to pull the submodules
git submodule update --init --recursive

# 2. Source the environment (see "Making the environment automatic" below to
#    avoid re-running this in every shell)
source setup.bash

# 3. Sync the host Python environment (required by tt-env-gen).
#    Add `--extra cu130` to also pull the CUDA 13.0 wheels for PyTorch
#    GPU work (or whatever CUDA version your driver supports, see
#    `pyproject.toml` for available dependency groups, e.g. `--extra cu128`
#    for CUDA 12.8, or `--extra cpu` if you do not have a CUDA-capable GPU).
#    This is only necessary if you want to run the gaze estimation
#    calibration pipeline on the host machine and need support for a
#    different CUDA version than the default one available through PyPI.
#    Otherwise you can run it in the Devcontainer or using the commander
#    container, both of which use the NVIDIA Container Runtime only when you
#    opt in with COMMANDER_RUNTIME=nvidia in .env (step 5).
uv sync            # or: uv sync --extra cu130

# 4. Generate the .env file (detects FLIR cameras / PulseAudio)
tt-env-gen

# 5. Edit .env to fill in your personal preferences (e.g. noVNC / Foxglove
#    ports) and your hardware: TEENSY_DEV, and COMMANDER_RUNTIME=nvidia if you
#    want the containers to have GPU access (see "GPU" below — it defaults to
#    runc and is NOT auto-detected).
nano .env          # or whatever editor you prefer

# 5b. Re-run tt-env-gen so the variables derived from your edits (UV_EXTRA,
#     NVIDIA_*) are regenerated to match.
tt-env-gen

# 6. Pull the prebuilt Docker images from Docker Hub (needs `docker login`).
#    `--profile='*'` selects every service so all images are pulled.
#    Do this BEFORE step 7: tt-build runs inside the `builder` image.
tt-compose --profile='*' pull

# 7. Build the ROS 2 workspace inside the builder container. Use `--all` the
#    first time so the external modules (moveit2, etc.) are built too; after
#    that, `tt-build colcon` (without `--all`) rebuilds just the tabletop
#    packages. Build the Foxglove plugin and firmware separately when you need
#    them (see Usage).
tt-build colcon --all
```

`setup.bash` is the single source of environment truth: it detects host vs.
container, activates the right uv virtualenv, sources ROS, and puts the
`tt-*` commands on your `PATH`.

!!! tip "Making the environment automatic"
    `source setup.bash` only affects the current shell. To avoid re-running it
    every time, either:

    - **Append it to your shell profile** so every new shell sources it:

        ```bash
        echo "source $(pwd)/setup.bash" >> ~/.bashrc
        ```

        Be aware this sets all the TableTop environment variables and activates
        the TableTop virtual environment for **every** bash session, which you
        may not want.

    - **Use [direnv](https://direnv.net/)** (recommended) to scope it to the
      repository. The repo ships a `.envrc` that sources `setup.bash`; once
      direnv is installed, run `direnv allow` in the repo once and the
      environment is set up automatically whenever you `cd` into the TableTop
      directory (and unset when you leave).

`.env` is used **exclusively** for variable substitution in `compose.yaml`
(device paths, ports, GPU runtime, PulseAudio mounts); Docker Compose reads it
and may pass selected values into the containers. Keeping these substitutions
in `.env` — rather than in your shell — is what lets the Dev Container be built
directly from VS Code while still resolving every `$VAR` in `compose.yaml`.
Re-run `tt-env-gen` whenever you plug or unplug hardware, since device paths are
baked into `.env`, and whenever you edit `COMMANDER_RUNTIME`, since `UV_EXTRA`
and the `NVIDIA_*` variables are derived from it.

## Docker images

The `jazlabtabletop/ros-base` and `jazlabtabletop/novnc` images are prebuilt and
pushed to Docker Hub; `tt-compose --profile='*' pull` fetches them (the
`--profile='*'` selects every service, so every image is pulled). `tt-compose
build` no longer builds anything — the image build moved to `docker-bake.hcl`.

!!! warning "Building images yourself is rarely needed and can break things"
    Building the images (rather than pulling them) may introduce breaking
    changes and should be avoided. If you genuinely need to, use `buildx bake`:

    ```bash
    docker buildx bake ros-base          # rebuild the ROS base image
    docker buildx bake ros-base --pull   # ...and refresh the upstream base image
    docker buildx bake novnc             # rebuild the noVNC image
    ```

    The `novnc` image should essentially never need rebuilding. The `ros-base`
    image only needs rebuilding if:

    1. You need extra **non-Python** dependencies for the existing ROS 2
       packages, or you add a new ROS 2 package whose `package.xml` declares
       dependencies beyond those already installed; **or**
    2. You need to update the git submodules to a more recent commit; **or**
    3. You need new apt packages and simply installing them in a new Dockerfile
       layer on top of the existing image would pull in incompatible versions.
       (This is why the ROS base image in the Dockerfile is intentionally not
       pinned: apt packages installed in the Dockerfile can conflict with
       packages already baked into the base image if that base is out of date.)

## Optional host setup

Driving the real hardware needs some persistent, privileged host configuration:
device udev rules (Teensy/Flic, FLIR cameras), a larger USB buffer for the FLIR
cameras, the `performance` CPU governor for real-time control, the **TableTop
network**, and the UR5e robot itself. All of this — with command examples for an
Ubuntu 24.04 **host machine** — is documented in
[Real Hardware Setup](real-hardware.md).

### GPU (NVIDIA container runtime)

GPU access for the `commander` and Dev Container is **opt-in and not
auto-detected**. A fresh `.env` ships `COMMANDER_RUNTIME=runc`, which runs those
containers on the default Docker runtime with CPU-only PyTorch wheels — even on
a machine with a working NVIDIA GPU.

To use the GPU, install the NVIDIA driver and
[NVIDIA Container Toolkit](https://docs.nvidia.com/datacenter/cloud-native/container-toolkit/install-guide.html)
from the [Requirements](#requirements) table, then edit **`.env`** (never
`.env.example`):

```bash
COMMANDER_RUNTIME=nvidia
CUDA_VERSION=130     # match your driver; see pyproject.toml for the available
                     # cu* extras (126, 128, 130)
```

and re-run `tt-env-gen`, which turns those into the `UV_EXTRA` (`--extra
cu130`) and `NVIDIA_VISIBLE_DEVICES` / `NVIDIA_DRIVER_CAPABILITIES` (`all`)
values that `compose.yaml` consumes:

```bash
tt-env-gen
```

Already-running containers keep the old runtime, so recreate them
(`tt-compose --profile=<sim|real> up --force-recreate`) after switching. Set it
back to `runc` to go CPU-only. `tt-env-gen` rejects any other value, and errors
if `COMMANDER_RUNTIME=nvidia` is paired with an empty `CUDA_VERSION`. Full
details, including the upgrade note for `.env` files written by the older
autodetecting `tt-env-gen`, are in
[Configuration](../guide/configuration.md#gpu-access-nvidia-container-runtime).

### Audio (reward sounds)

Reward sounds need PipeWire/PulseAudio on the host so audio can pass through to
the container. Install per your OS/distro-specific instructions. For Ubuntu and
MacOS, the following will typically suffice:

```bash
# Ubuntu (PipeWire as the modern PulseAudio replacement)
# This uninstalls the deprecated `pipewire-media-session` package if it was
# previously installed and installs `wireplumber`, which supersedes it.
# Remove `pipewire-media-session-` from the install command below if you need
# this package for any reason (you probably don't, since `wireplumber` should
# be a drop-in replacement).
sudo apt update
sudo apt install -y pipewire-pulse wireplumber pipewire-audio-client-libraries pipewire-media-session-
systemctl --user --now enable wireplumber.service

# macOS
brew install pulseaudio
brew services start pulseaudio
```

### Firmware

Firmware (Teensy + Flic micro-controllers) is built and flashed from the host
with:

```bash
tt-build microros
```

The host `tt-build` runs inside the privileged `builder` container (with `/dev`
mounted), so it can flash over USB. This does **not** work from inside the Dev
Container, which is unprivileged and does not mount `/dev`.

!!! tip "First upload usually fails"
    `tt-build microros` retries the build/upload twice. On our rig — a quirk of
    this particular Teensy and our PlatformIO upload setup — the first attempt
    almost always builds successfully but fails to *upload*; the second attempt
    almost always succeeds. It is expected and nothing you need to act on.

!!! note "PlatformIO Docker volume ownership"
    The `platformio-core` Docker volume is created and owned by the first user
    to run `tt-build microros`.  If a different user then tries to build, they
    will get permission errors inside the container.  The fix is to delete the
    volume and let it be recreated:

    ```bash
    docker volume rm tabletop_platformio-core
    tt-build microros
    ```

!!! note "Flic Micro firmware is incomplete"
    The Teensy is the only currently supported micro-controller.
    The Flic Micro firmware is **incomplete** and has no launch file,
    `tt-launch` entry, or Docker compose service; if you need it, you
    can add a launch file nearly identical to `teensy.launch.py` with
    a different micro-ROS agent node name and device path, then create
    an entry in `bin/container/tt-launch` and a service in `compose.yaml`.
    See [Architecture §5.1](../architecture.md).

## Next steps

- [Usage](usage.md) — build, start containers, run a task.
- [CLI & Tooling](../guide/cli.md) — the full `tt-*` command set.

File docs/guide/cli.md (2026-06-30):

# CLI & Tooling

Sourcing `setup.bash` puts the `tt-*` commands on your `PATH`. They are split
by where they run: `bin/common` (both), and `bin/host` or `bin/container`
depending on context. Under the hood, the host wrappers mostly shell out to
`docker compose` (regenerating `.env` first). See
[Architecture §2.2](../architecture.md) for exactly what each one runs.

## Host commands (`bin/host`)

| Command | Description |
| --- | --- |
| `tt-compose` | Wrapper for `docker compose` with TableTop defaults (generates `.env` if missing) |
| `tt-build` | Build a component (`colcon`/`microros`/`foxglove`) via the privileged `builder` container |
| `tt-env-gen` | Generate `.env` from `.env.example` with hardware detection |
| `tt-attach` | Open a shell in a compose service (a fresh container by default; `-e` to reuse a running one) |
| `tt-flir-reset` | Reset FLIR cameras (reload udev, factory reset, regenerate env) |

!!! note "Host setup"
    Real-hardware host configuration (udev rules, USB buffer size, CPU
    governor, the TableTop network, URCaps) is documented as Ubuntu 24.04
    procedures in [Real Hardware Setup](../getting-started/real-hardware.md),
    not shipped as `tt-*` commands or scripts.

## Container commands (`bin/container`)

| Command | Description |
| --- | --- |
| `tt-build` | Build a component: `colcon` (workspace), `microros` (firmware), or `foxglove` (plugin) |
| `tt-launch` | Launch ROS 2 nodes (commander, tasks, dual_ur, …) |
| `tt-kill-ros` | Kill all running ROS 2 processes |

## Common commands (`bin/common`)

| Command | Description |
| --- | --- |
| `tt-clean` | Clean build artifacts, logs, caches, etc. (by flag) |

## `tt-build` components

`tt-build <component> [options…]`, where `<component>` is one of:

| Component | Builds |
| --- | --- |
| `colcon` | the ROS 2 workspace (colcon) |
| `microros` | the Teensy micro-controller firmware (PlatformIO) |
| `foxglove` | the Foxglove MoveIt converter plugin (`.foxe` written to `$TABLETOP_DIR`) |

!!! note "First build"
    Run `tt-build colcon --all` once to build the external modules (moveit2,
    etc.) as well; afterwards `tt-build colcon` rebuilds just the tabletop
    packages. There is no `all` component — build `microros` and `foxglove`
    separately when you need them.

### `colcon` options

```text
-c, --clean-tabletop   Clean tabletop packages before building
--clean-all            Clean the entire workspace before building
--clean-cmake          Clear CMake caches before building
-a, --all              Build all packages (tabletop + modules, e.g. moveit2)
-p, --packages-up-to   Build the given packages and their dependencies
-m, --only-modules     Build only external modules
-w, --workers N        Limit parallel workers (low-memory systems)
--build-debug          Build with debug symbols (default: release)
--clang                Use clang (default: gcc)
--linker NAME          Linker to use (default: mold)
-v, --verbose          Verbose build output
```

### `microros` options

```text
--clean                Clean the micro-ROS build directory first
--no-upload            Build only (no upload)
--compiledb            Generate compile_commands.json for IDE integration
```

### `foxglove` options

```text
-o, --output <path>    Where to write the packaged .foxe (default: $TABLETOP_DIR).
                       A directory keeps the packaged name; a path ending in
                       .foxe renames the plugin to it.
```

## `tt-launch` targets

`tt-launch` runs inside a container — open one with `tt-attach <service>` (or use
the Dev Container), or run it as a one-shot from the host by prefixing it with
`tt-compose run --rm commander`. `tt-launch <target> [ros2 launch args…]`.
Each target maps to a single launch file — `tt-launch` is a thin `ros2 launch`
wrapper. Targets: `commander`, `tasks`,
`dual_ur`, `teensy`, `flic`, `eyelink`, `flir_no_sync`, `flir_synchronized`,
`flir_calibrate`, `optitrack`, `rosbag`, `rviz`, `foxglove`, `moveit`.

```bash
tt-launch tasks task:=foraging_ordered robot_mode:=mock
tt-launch commander robot_mode:=real
tt-launch teensy simulate:=true
```

!!! note "No aggregate `rig` target"
    The old `tt-launch rig` (which started every subsystem at once via
    `rig.launch.py`) was retired. Bring the rig up with a Compose profile
    (`tt-compose --profile=sim up` / `=real`) — each subsystem runs in its own
    service — then run `tt-launch tasks …` on top. See
    [Usage → Starting containers](../getting-started/usage.md#starting-containers-profiles).

## Bag conversion (`unbag`)

To export a recorded session bag to per-topic CSVs and decoded images, use the
standalone C++ exporter (built by `tt-build colcon`):

```bash
ros2 run tabletop_unbag unbag /path/to/session/bag        # → <parent>/unbag/
```

`unbag` supersedes the legacy Python `rosbag_to_csv` converter (whose
`tt-launch` target was removed; it is slated for retirement). See
[Usage → Converting recorded bags](../getting-started/usage.md#converting-recorded-bags),
with the full option set in `src/ros/tabletop/tabletop_unbag/README.md`.

## Python CLI tools

Installed as entry points (available after sourcing `setup.bash`):

| Command | Description |
| --- | --- |
| `tt-gaze-calibrate` | Full gaze calibration pipeline |
| `tt-gaze-preprocess` | Preprocess eye-tracking + marker data |
| `tt-gaze-train` | Train the gaze estimation model |
| `tt-gaze-predict` | Predict gaze on a new session |
| `tt-gaze-visualize` | Visualize calibration data and predictions |
| `tt-flic-scapy` | Flic button client using a raw scapy BLE sniffer |

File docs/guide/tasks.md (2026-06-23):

# Tasks & Experiments

A **task** is a behavioral experiment. Tasks live in `tabletop_tasks` and drive
the rig through the `Commander`; they never touch devices directly.

## How a task runs

```text
tasks.launch.py  (task:=<name>  ⇒  coro_config = config/<name>.yaml)
  └─ run.py: run_tasks(commander, config_file)
       loads tasks: [{class, kwargs}, …] from the YAML
         └─ tasks/<paradigm>.py   (BaseObjectInteractionTask subclass)
              trial_generator → TrialSpec → run_trial() → TrialFeedback
                 └─ trial_generators/<generator>.py
```

`run_tasks` instantiates each task class with its `kwargs` (plus the injected
`Commander`) and awaits its run loop. The generic trial loop pulls a
`TrialSpec` from a **trial generator**, runs it, and feeds a `TrialFeedback`
back into the generator via its `send()` method — so the next trial can depend
on the subject's last response (e.g. alternating or blocked designs).

## Task paradigms

| Task class | Config prefix | Behavior |
| --- | --- | --- |
| `ForagingTask` | `foraging_*` | Subject selects among presented objects |
| `PresentTask` | `present_*` | Passive object presentation |
| `SmoothPursuitTask` | `smooth_pursuit_*` | Object follows a trajectory for the subject to track |
| `DummyTask` | `dummy` | Diagnostic scratchpad (latency / motion / component checks) |

## Trial generators

Generators implement an iterator + `send(trial_spec, feedback)` protocol:
`BaseTrialGenerator` plus `OrderedChoiceAlternating` and
`RandomChoiceAlternating`, which alternate between robot groups (left/right).
The config's `trial_generator` key selects one and supplies its kwargs (object
groups, poses, occlusion probability, …).

## Configuring a task

Task configs are YAML files in `tabletop_tasks/config/`. Each lists one or more
`{class, kwargs}` entries; the kwargs map directly to the task class
constructor. Available configs:

| Config | Task | Notes |
| --- | --- | --- |
| `foraging_ordered.yaml` / `foraging_random.yaml` | ForagingTask | ordered / randomized trials |
| `present_ordered.yaml` / `present_random.yaml` | PresentTask | ordered / randomized presentation |
| `smooth_pursuit_random.yaml` | SmoothPursuitTask | random waypoints |
| `smooth_pursuit_spiral{,_test}.yaml` | SmoothPursuitTask | helical trajectory |
| `smooth_pursuit_sin.yaml` | SmoothPursuitTask | sinusoidal trajectory |
| `dummy.yaml` | DummyTask | diagnostic scratchpad |

To create a new task, copy an existing config and adjust the kwargs. Every
config is commented inline; the class definitions in
`tabletop_tasks/tabletop_tasks/tasks/` and the generators in
`trial_generators/` are the source of truth for available parameters (see the
[API Reference](../reference/tabletop_tasks.md)).

```bash
tt-launch tasks task:=foraging_ordered robot_mode:=mock
```

!!! tip "Robot already holding an object?"
    If the arm starts a session holding a grid object, tell the commander which
    grid index it holds: `tt-launch tasks initial_object:=5,0 …` (or just put
    the object back yourself).

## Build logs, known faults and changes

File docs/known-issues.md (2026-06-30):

# Known Issues

Discrepancies between code, configuration, and documentation, plus tracked
`TODO`s and pending functional work, flagged for maintainer review.

> **2026-06-29 reconciliation.** All of **Wave 1** of the fix plan
> (`docs/fix-plan.md`) has been merged into `main` (PRs #19–#30), and the
> `tabletop_unbag` bag→CSV/image converter (PR #17) was added. This file has been
> reconciled against that state:
>
> - Items fixed in Wave 1 moved to [Resolved in Wave 1](#resolved-in-wave-1-2026-06)
>   with their PR numbers.
> - The items that remain **open** — by design, or scheduled for Wave 2 — are
>   listed first.
> - Earlier deprecation-branch history is unchanged at the bottom.
>
> Each formerly-open item was re-verified by *content* against `main`, not just
> by commit title.
>
> **2026-06-30 update (PR review).** The three items that were awaiting hardware
> validation — UR `safety_restart` recovery, the Teensy safety firmware (#30),
> and the Eyelink stale-sample drain — have been **confirmed on real hardware**
> and are now resolved. The `tasks.launch.py` `rosbag` default was confirmed
> intended `false` and the docstring fixed. Two new Wave-2 items were added
> (Open §B5/§B6), and `tt-launch` was reduced to a pure `ros2 launch` wrapper
> (the `rosbag_convert` and `discovery` targets were removed).

---

## Open issues

### A. Open by design / deferred

1. **smooth-pursuit teleports the object onto the gripper (design decision).**
    `tasks/smooth_pursuit.py` still calls `manually_attach_object` instead of
    `await manipulator.fetch_object(...)` (the real fetch is commented out, with
    the `# TODO: FIX!!!` and follow-on `plan_and_move("fetched")`
    `# TODO: Maybe remove` deliberately retained). Whether to keep the
    smooth-pursuit object in the grid and physically pick it, or manually attach
    it at task start, is an unresolved design decision — kept open intentionally.

2. **`nodes/flic.py:323` publishes the response on a generic message type**
    (`# TODO: Change to custom message`). Deferred from the PR #26 cleanup: it is
    a feature addition needing a new `tabletop_interfaces` `.msg` and a colcon
    rebuild, out of scope for a comment cleanup.

### B. Larger refactors (Wave 2)

3. **`group_name` vs `robot_name` conflation.** Tasks, trial specs, and trial
    generators pass `group_name` where they should pass `robot_name` (the
    commander looks up a manipulation context manager by robot name, not MoveIt
    group name; they happen to be equal today). Make `robot_name` the task-facing
    parameter and keep `group_name` a property of the controlled robot. Touches
    `tabletop_tasks` plus the `ObjectManipulationInterface` /
    `PlanAndExecuteInterface` plumbing — see `fix-plan.md` WT-I.

4. **Arm-lock terminology is mechanism-specific.** The rig currently uses a
    **button per hand** (unpressed = the hand is free) plus a per-arm buzzer to
    cue which hand to use; a physical arm lock may be added later. The wording
    "electromagnetic arm lock" (e.g. `interfaces/teensy.py`) and the
    `SetArmLock` / `*_arm_lock*` naming across `tabletop_interfaces`, firmware,
    `commander.yaml`, and docs is inaccurate. The safety gate is now
    *configurable* (`safe_to_execute.require_arm_locks`, see Resolved §B3) but
    still uses this naming. Reword repo-wide to be agnostic to the hold/detect
    mechanism — see `fix-plan.md` WT-N.

5. **Safe-execution should gate on the presentation region, not the manipulation
    state.** The current safety stop checks whether the arm is in the `PRESENT`
    manipulation state to decide whether motion must be prevented. But while the
    object is actually being presented the arm is still in the `FETCHED` state,
    so the subject can be within reach during that window. Gate safe-execution on
    whether the arm has **acquired the presentation region** (cf. the
    `object_manipulation.py:1759 # TODO: Check if robot is in presentation
    region` marker in §C), not on the manipulation-state label alone.
    Safety-relevant — see `fix-plan.md` WT-O.

6. **Retire the legacy Python bag converter.** Move
    `tabletop_rig/utils/rosbag.py` (`rosbag_to_csv`) to `deprecated/`, and stop
    the gaze-estimation calibration scripts from importing it to convert bags
    themselves. Instead, the operator unbags the gaze/marker data with
    `tabletop_unbag` (`unbag`) first, and calibration consumes the resulting CSVs.
    (The `rosbag_convert` `tt-launch` target was already removed; the entry point
    and the calibration import remain until this lands.) See `fix-plan.md` WT-P.

### C. Low-priority "decide later" markers (P4)

Investigate or delete; no known breakage. Still present after Wave 1:

- `compose.yaml:203` — `SYS_NICE # TODO: see if needed` on the commander service.
- `interfaces/moveit/moveit.py:465` — `# TODO: Should probably use this`.
- `interfaces/moveit/plan_and_execute.py:628` — `# TODO: Maybe revalidate`.
- `interfaces/ur.py:542` — `# TODO: See if this is necessary`.
- `interfaces/moveit/object_manipulation.py:1759` — `# TODO: Check if robot is
  in presentation region`.

(The `moveit_controllers.yaml`, `moveit.launch.py` / `rviz.launch.py` `to_dict()`,
and `gaze/preprocess.py` markers from the previous list were resolved — see
Resolved §F.)

---

## Resolved in Wave 1 (2026-06)

Every item below was open at the 2026-06-24 triage and is now fixed on `main`.
Grouped by the original section, with the merging PR.

### A. Likely bugs

- **Executor leaked `ConditionReachedException`** → **#25.**
  `AIOExecutor.spin_until_future_complete` now catches the signal internally
  (bare or `ExceptionGroup`-wrapped) and returns cleanly; the
  `system_check.py` `except*` workaround was removed.
- **Copy-paste parameter bug** (`plan_and_execute.py`) → **#19.**
  `allowed_duration_margin` now reads `execution.allowed_duration_margin`.
- **Dropped `use_cache=False` on reset** (`object_manipulation.py`) → **#19.**
  The `use_cache=False` copy of `reset_request` is now the one passed to
  `plan_and_execute`, so the reset path no longer reads a stale cached
  trajectory.

### B. Config

1. **Typo'd joint name** in `commander.yaml` `test_object_attached` → **#22.**
   `left_eblow_joint` / `right_eblow_joint` corrected to `*_elbow_joint`.
2. **Unread config parameters** → **#22.** `trajectory_cache.base_link_name` and
   `execution.moved_tolerance` were confirmed to have no reader and were deleted
   as dead config.
3. **Arm-lock safety check** (`teensy.py::_msg_safe_to_execute`) → **#30 / #22.**
   Per the maintainer decision, the gate was **not** force-re-enabled; instead it
   is now configurable via `safe_to_execute.require_arm_locks` in
   `commander.yaml`, defaulting to `false` (laser-only) to preserve existing
   behaviour. (Validated on real hardware; mechanism-agnostic rename is Open §B4.)
4. **Duplicate Flic MAC** for `big_object_3` / `big_object_7` / `small_object_0`
   → **intentional.** Confirmed by the maintainer as deliberately shared
   (spare/unassigned); left unchanged.
5. **`gaze_estimation_geometric.yaml` keys out of sync** → **#23.** Realigned to
   `gaze_estimation.yaml`: `data:` → `dataloaders:`, and the `visualize:` block
   now uses `animate_2d_dots` / `animate_3d_dots`. The two configs are now
   identical except the `model:` block (model-creation parameters).

### C. Firmware

1. **Teensy pin "conflict"** (`LEFT_ARM_LOCK_STATE_PIN`) → **#30.** Resolved as
   *intentional*: pin 38 is deliberate because pin 36 is `BUTTON_STATE_PIN`; the
   stale `// TODO: change back to 36` was removed and the rationale documented.
2. **Misspelled enum `UNCRECOVERABLE_ERROR`** → **#30.** Renamed to
   `UNRECOVERABLE_ERROR` throughout.

### D. Code smells / API warts

1. **`Commander.manually_atatch_object`** → **#21.** Renamed to
   `manually_attach_object`; both call sites (`smooth_pursuit.py`, `dummy.py`)
   updated in the same commit; the deprecated alias was not kept.
2. **`ur.py::stop_program()` ignored its future** → **#20.** Now tracks the
   rclpy future across calls (skip while pending, retry on failure, suppress
   until `reset()`).
3. **`executors.py` bare `print`** → **#25.** Exceptions now go through the
   node/ROS logger.

### E. Functional issues from `todo.md`

1. **First-trial false "laser broken"** → **#30** (debounce-init fix; **validated
   on real hardware** 2026-06-30).
2. **Debounce ISRs read epoch-synced time** → **#30** (latched monotonic time;
   validated with the firmware bench check above).
3. **UR `safety_restart` recovery** → **#20** + recovery-state-machine reconnect
   (`ur.py::_reconnect`); **validated on the real robot** 2026-06-30.
4. **Unverified bringup parameter warnings** → **#29.** `fallback_controllers`
   silenced via an explicit empty list in `dual_controllers.yaml`;
   `publish_robot_description_semantic` set `False` on the rviz/moveit
   visualization nodes (and `True` only on the commander).
5. **`group_name` vs `robot_name`** → still open, Wave 2 (Open §B3).
6. **Retire `rig.launch.py`; flatten `tasks.launch.py`** → **#29.**
   `rig.launch.py` moved to `deprecated/launch/`; `tasks.launch.py` now includes
   `commander.launch.py` / `rosbag.launch.py` directly; the `tt-launch rig`
   target and the unscoped-group `TODO`s were removed.

### F. Source TODOs and P4 markers

- **`foraging.py` response-phase `release_arm`** → **#21.** Per decision, the
  unconditional `release_arm(arm)` was kept and the `# TODO: Remove!!!` removed.
- **Eyelink node TODOs** (`:397` callback groups, `:915` stale samples, `:926`
  "verify this fix", `:213/717` tuning, `:1402` content-free) → **#26.** All
  resolved (callback-group rationale documented; stale-sample drain implemented
  and **validated on a live Eyelink** 2026-06-30; dead comments removed).
- **`moveit_controllers.yaml:13`**, **`moveit.launch.py` / `rviz.launch.py`
  `to_dict()`** → **#29** (kept with documented rationale).
- **`gaze/preprocess.py` marker** → resolved (no TODO remains in that file).

### G. Build / developer-environment

All → **#24:** `mingus` moved to `[project].dependencies`; the GitHub CLI
devcontainer feature added; `docker-bake.hcl` made multi-platform
(`linux/amd64` + `linux/arm64`); `.vscode/c_cpp_properties.json` `pio_teensy`
path fixed and the stale `pio_sniffer` config removed.

### H. Documentation gaps

- **`TeensySensor.msg` header** (wrong package, hard-coded "100 Hz") → **#28.**
- **`deprecated/README.md` stale paths** → **#28 / #29** (flic-micro path and the
  new `launch/rig.launch.py` entry).
- **`bin/` scripts had no `-h|--help`** → **#27.**
- **Per-node/interface parameters not in published docs** → **#28**
  (`docs/guide/parameters.md`).
- **Missing FLIR GenICam reference**, **Foxglove layouts not in repo**, **setup
  gaps** (git-lfs/jq, reboot after `usermod -aG docker`, platformio-core volume
  ownership) → **#28** (`share/foxglove/*.json`, setup/usage docs).
- **`tabletop_unbag` (PR #17) undocumented globally** → resolved in this PR:
  added to `CLAUDE.md`, `architecture.md` (§5.5), `cli.md`, and
  `usage.md` (*Converting recorded bags*); package detail stays in
  `tabletop_unbag/README.md`.
- **`CLAUDE.md` / docs stale after the launch refactor** (the retired
  `tt-launch rig` target, the "arm-lock commented out" safety note, the
  "Teensy & Flic firmware" label) → resolved in this PR.
- **`tasks.launch.py` `rosbag` default doc/code drift** → resolved in this PR:
  the intended default is `false`, so the docstring was corrected to match the
  `default_value="false"` declaration (recording off unless `rosbag:=true`).
- **`tt-launch` simplified to a pure `ros2 launch` wrapper** → resolved in this
  PR (per review): the `rosbag_convert`/`rosbag_to_csv` target and the unused
  FastDDS `discovery` target were removed, and with them the `EXEC`/`RUN`
  dispatch machinery. Docs (`CLAUDE.md`, `cli.md`, `usage.md`, `architecture.md`)
  updated to match. (`discovery` was removed outright, not deprecated.)

---

## Resolved in the deprecation/cleanup branch

The following previously flagged items are no longer open — the relevant code
was removed or retired to `deprecated/` (see `deprecated/README.md`):

- **`commander_pretty.yaml`** (an unconsumed alternate of `commander.yaml`) was
  removed.
- **`bin/container/tt-create-graph`** — besides its earlier fixes (it referenced
  a non-existent style-config path and dropped all nodes when the ignore-list
  was empty), the script and its `ros_graph_style.yaml` were retired to
  `deprecated/ros-graph/`.
- **`trial_generators/blocked_cup_drawer.py`** (the inverted "correct" counter)
  was removed along with the non-alternating `ordered_choice` / `random_choice`
  generators; the surviving `*_alternating` variants are the supported path.
- **`tabletop_flic_micro` firmware** (the `resetButtonAds()` main-loop block)
  was retired to `deprecated/flic-button/`, superseded by the in-process scapy
  BLE sniffer.
- **`musings.md`** (which referenced many commands/scripts that no longer exist)
  was removed; its still-relevant troubleshooting content lives in
  [Troubleshooting](guide/troubleshooting.md) with the current command set.

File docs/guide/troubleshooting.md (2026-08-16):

# Troubleshooting

Battle-tested notes for the current command set. For a symptom →
starting-point table, see
[Architecture §6](../architecture.md). Known code/config bugs are tracked in
[Known Issues](../known-issues.md).

## Quick reference

```bash
# Host
source setup.bash                          # set up environment (add to ~/.bashrc)
tt-env-gen                                  # (re)generate .env after hardware changes
tt-compose --profile='*' pull              # pull the prebuilt Docker images (all services)
tt-build colcon --all                      # build the full workspace (modules incl.) — first build
tt-compose --profile=sim up                # start a simulation session

# Inside a container (or Dev Container)
tt-build colcon                            # build tabletop packages
tt-build colcon --clean-tabletop           # clean rebuild
tt-launch commander robot_mode:=mock       # commander only (rig comes from the compose profile)
tt-launch tasks task:=foraging_ordered     # run a task (starts a commander too)
```

## Docker

- **Containers rebuilding independently / stale layers.** Stop everything
  (`tt-compose --profile=<p> down`, or `docker container stop $(docker ps -q)`),
  then prune project artifacts with `docker system prune -af` (optionally
  `--volumes`), re-pull the images with `tt-compose --profile='*' pull`, and
  rebuild the workspace with `tt-build colcon --all`. Be aware the prune clears
  build cache for *all* Docker projects on the machine.

## Build

- **Computer freezes while building.** You're out of memory — too many packages
  × workers building at once. Limit parallelism:

    ```bash
    tt-build colcon --workers 1   # single-threaded (slow but safe)
    tt-build colcon --workers 2   # compromise
    ```

## Editor (Dev Container)

- **`Unable to connect to VS Code server: connect ENOENT`** when running
  `code <path>` / `cursor <path>` inside the Dev Container: open a new terminal
  and run it again.
- **Debugging:** use the VS Code debugger (launch configs are already set up) —
  you don't need `gdb -ex` or a debug build. If something is placed (or absent)
  for a non-obvious reason, it was probably deliberate; check git history before
  "fixing" it.

## ROS

- **Visualize the URDF:**

    ```bash
    ros2 launch tabletop_description dual_view_robot.launch.py
    ```

- **Mock-hardware demo:** there is no single `rig` launch anymore — bring up the
  `sim` profile (mock UR, teensy-sim, flic-sim, eyelink-sim, rviz) and run a task
  on top:

    ```bash
    tt-compose --profile=sim up
    tt-compose run --rm commander tt-launch tasks task:=foraging_ordered
    ```

    To launch one mock subsystem on its own instead, use its target directly,
    e.g. `tt-launch teensy simulate:=true` or `tt-launch flic simulate:=true`.

- **Commander executor.** Don't run the Commander on the `AIOExecutor` — its
  services intermittently stop responding. The Commander must use the
  thread-based executor, and the rclpy executor must run in a *separate thread*
  from the asyncio loop. See [Architecture §5.2](../architecture.md) and the
  signal-handling notes below.

## Commander / tasks

- **Robot is holding a grid object at trial start.** Either tell the commander
  which grid index it holds — `tt-launch tasks initial_object:=5,0 …` — or place
  the object back manually before starting.

## Flic buttons

The current `flic` node sniffs BLE directly with scapy; the old `flicd` daemon
container has been **removed** (its definition is preserved in
`deprecated/compose-services.yaml`). Most remaining pain is host Bluetooth.

- **`No such device` on startup / no `/flic` node in the ROS graph.** The host
  has no `hci0`: the Bluetooth hardware is present but the kernel drivers never
  initialized it, so there is no controller for the node to open. Check the host
  first — this is not a container problem:

    ```bash
    ls /sys/class/bluetooth/     # empty means no adapter; expect hci0
    ```

    If it is empty, load the drivers (`btusb` plus your vendor module —
    `btintel` for Intel AX2xx, `btrtl`/`btbcm`/`btmtk` for others) and restart
    the container:

    ```bash
    sudo modprobe btusb
    sudo modprobe btintel
    ls /sys/class/bluetooth/                 # hci0 should now appear
    tt-compose --profile=real restart flic
    ```

    Full walkthrough, including how to make it stick across reboots:
    [Real Hardware → Bluetooth adapter](../getting-started/real-hardware.md#bluetooth-adapter-flic-buttons).

- **Free the Bluetooth adapter** (the host BlueZ stack can hold it). This is the
  *other* failure mode: `hci0` exists, but something else owns it — the node
  takes exclusive HCI user-channel access and cannot share:

    ```bash
    sudo systemctl stop bluetooth
    sudo systemctl disable bluetooth     # and set AutoEnable=false in
                                         # /etc/bluetooth/main.conf to keep it off
    ```

- **Bluetooth device not found / won't connect.** Restart the machine (sometimes
  twice). The `flic` container needs the `NET_ADMIN` capability for raw packet
  capture (already set in `compose.yaml`).

- **Last-resort Bluetooth incantations:**

    ```bash
    sudo modprobe -r btusb && sudo modprobe btusb   # reload the driver
    rfkill unblock bluetooth                          # unblock
    hciconfig hci0 reset                              # reset adapter
    btmgmt info                                       # adapter info
    ```

- **FlicPiano.** For stress relief, the retired `deprecated/flic-button/piano.py`
  plays notes from button presses (needs the `mingus` package from the `dev`
  dependency group). It targets the old `flicd`-based client; see
  `deprecated/README.md`.

## Teensy

- **After changing firmware,** make sure the micro-ROS `executor` is initialized
  with the correct number of handles (and `colcon.meta` matches), then rebuild:

    ```bash
    tt-build microros
    ```

- **Serial debugging:** attach to the device with PlatformIO from a container
  that has it mounted, e.g. `pio device monitor -p "$TEENSY_DEV"`.
- **Device not mounted in Docker:** regenerate `.env` after plugging it in so
  the device path is captured: `tt-env-gen`. When in doubt, unplug and replug.

## Robot (UR5e)

- **Calibration is saved on the robot.** Re-running the extraction does not
  change a stored calibration. The per-arm `*_calibration.yaml` files in
  `tabletop_description/config/` are machine-generated — don't hand-edit them.
- **"Joint … from the starting state is outside bounds".** The arm was moved
  into a configuration outside the controller's valid range. Manually move it
  back into bounds (you may need to spin the joint fully around).
- **Robot pose looks off relative to the rig.** The ground is a reliable
  reference point.
- **Protective stops during object resets.** Tune the reset request's
  `velocity_scaling_factor` / `acceleration_scaling_factor` in the relevant
  `object_reset/*.yaml` to soften jerky motion.

## Environment & configuration

- **`tt-*` command not found** → you didn't `source setup.bash` (add it to
  `~/.bashrc`).
- **Docker can't see a device** (FLIR/Teensy) → `tt-env-gen --clean`, then check
  `.env` and `tt-compose ps`.
- **`.env` missing/corrupt** → `tt-env-gen --clean` regenerates it from
  `.env.example`.
- **No GPU inside the commander / Dev Container** (`nvidia-smi` missing, torch
  reports no CUDA) → GPU access is opt-in and **not** autodetected. Set
  `COMMANDER_RUNTIME=nvidia` (and a `CUDA_VERSION` your driver supports) in
  `.env`, re-run `tt-env-gen` so `UV_EXTRA`/`NVIDIA_*` are regenerated, then
  recreate the container (`tt-compose --profile=<sim|real> up
  --force-recreate`) — a running container keeps the runtime it started with.
  See [Configuration](configuration.md#gpu-access-nvidia-container-runtime).
- **`unknown or invalid runtime name: nvidia`** → `COMMANDER_RUNTIME=nvidia`
  but the [NVIDIA Container
  Toolkit](https://docs.nvidia.com/datacenter/cloud-native/container-toolkit/install-guide.html)
  isn't installed/registered with Docker. Install it (`docker info | grep -i
  runtimes` should list `nvidia`) or set `COMMANDER_RUNTIME=runc` and re-run
  `tt-env-gen`.
- **`COMMANDER_RUNTIME must be set to 'runc' or 'nvidia'`** (or the matching
  `CUDA_VERSION` error) → `tt-env-gen` validating `.env`; fix the value in
  `.env`, not in `.env.example`.
- Prefer the `tt-compose` wrapper over raw `docker compose` — it sets up the
  environment for you.

## Gaze estimation

Run the pipeline steps individually for debugging:

```bash
tt-gaze-preprocess -d /path/to/session --visualize
tt-gaze-train -d /path/to/session
tt-gaze-visualize -d /path/to/session
```

If training stalls or loss won't drop, check that preprocessing produced no
NaNs, that EyeLink and OptiTrack data are synchronized, and that the config
hyperparameters are sane. To convert an EyeLink EDF to CSV (needs `edf2asc` from
the EyeLink Developers Kit):

```bash
python -m tabletop_py.gaze.edf recording.edf -o recording.csv
```

## FLIR cameras

Make sure the host is configured for the cameras (USB buffer size and
`/dev/flir/*` udev symlinks) per
[Real Hardware Setup → Host configuration](../getting-started/real-hardware.md#host-configuration-ubuntu-2404),
then capture the device paths:

```bash
tt-env-gen                               # capture FLIR_DEV_* into .env
```

If cameras misbehave, `tt-flir-reset` reloads udev, factory-resets, and
regenerates the env. Check synchronization with `ros2 run tabletop_rig system_check`.

## Performance

For real-time control, pin the CPU to the `performance` governor (see
[Real Hardware Setup → CPU governor](../getting-started/real-hardware.md#cpu-governor-real-time-control)).
Build/clean helpers:

```bash
tt-build colcon --workers 1|2                      # avoid build OOM
tt-clean --tabletop-colcon                         # clean tabletop build
tt-clean --all-colcon                              # clean all colcon builds
tt-clean --logs                                    # clean logs
tt-clean --tabletop-cache                          # clean planning/trajectory caches
```

## Architecture deep-dives

### Commander signal handling

Clean Commander shutdown was hard-won:

- **MoveItPy** installs its own signal handler — construct it asking it *not* to.
- **rclpy** installs its own handler too — call `rclpy.init` after `asyncio.run`,
  or with `SignalHandlerOptions.NO`.
- `moveit_py` `execute_and_wait` / `stop_execution` **hang** if the UR
  controllers stop at the same time as the Commander. This happens when you
  launch the driver in the same process (`rig`/`tasks` with `ur_launch:=true`).
  **Run the UR driver in its own container/process.**

### Planning (smooth pursuit / ConcatPlanRequest)

A long freeze during TOTG post-processing usually means too many waypoints in a
`ConcatPlanRequest`. If you need many waypoints, disable
`post_process_after_concat`.

### Sound

No audio in the Dev Container usually means the PulseAudio port changed. Rebuild
the Dev Container, or run from the host via `tt-launch` (which re-detects the
socket through `tt-env-gen`).

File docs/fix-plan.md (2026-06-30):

# TODO / Known-Issues Fix Plan

This plan triaged every open `TODO` comment in tracked source, every entry in
`docs/known-issues.md`, and every item in the maintainer's `todo.md`, then
grouped the fixes into **independent worktrees** runnable in parallel. It is the
companion to `docs/known-issues.md`.

Original triage was against `main` @ `3e9d697` (2026-06-24).

---

## 1. Status (updated 2026-06-29)

**Wave 1 is fully merged into `main`** (PRs #19–#30), and the `tabletop_unbag`
converter (PR #17, not originally in the plan) was added. The
docs/CLAUDE.md/known-issues reconciliation pass (this PR) is what closes Wave 1.

| Worktree | PR | Status |
| --- | --- | --- |
| WT-A · moveit interface bug fixes | #19 | ✅ merged |
| WT-C · UR `stop_program` future (P1) | #20 | ✅ merged |
| WT-D · rename + task-logic decisions | #21 | ✅ merged |
| WT-E · `commander.yaml` config | #22 | ✅ merged |
| WT-F · gaze geometric config | #23 | ✅ merged |
| WT-J · build / dev-env | #24 | ✅ merged |
| WT-B · executor robustness | #25 | ✅ merged |
| WT-M · eyelink/flic node TODOs | #26 | ✅ merged |
| WT-K · `bin/` script help | #27 | ✅ merged |
| WT-L · documentation | #28 | ✅ merged |
| WT-H · launch refactor | #29 | ✅ merged |
| WT-G · Teensy firmware + safety gate | #30 | ✅ merged |

All Section 6 maintainer decisions were answered and applied. The per-worktree
detail is preserved in [Section 4](#4-wave-1-worktrees-completed) for provenance.

**2026-06-30 (PR review):** the three items that had landed but were awaiting
hardware validation — UR `safety_restart` recovery (WT-C P2), the Teensy safety
firmware (WT-G, #30), and the Eyelink stale-sample drain (WT-M, #26) — are now
**confirmed on real hardware** and fully closed. The `tasks.launch.py` `rosbag`
default was confirmed intended `false` (docstring fixed to match the code).

---

## 2. Remaining work (re-prioritized)

Wave 1 closed the quick bug fixes and doc inconsistencies, and the three items
that had been awaiting hardware validation are now **confirmed on real
hardware** (2026-06-30 — see §1). What's left is one **safety** improvement,
the **Wave-2 refactors**, one deferred feature, and P4 cleanup. Re-prioritized
by risk / what unblocks the most:

### P1 — Safety

1. **WT-O · gate safe-execution on the presentation region, not the
   manipulation state.** The safety stop currently keys on the `PRESENT`
   manipulation state, but the arm is still in `FETCHED` while it actually
   presents the object, so the subject can be within reach during that window.
   Gate on whether the arm has **acquired the presentation region** instead.
   This is the real fix behind the `object_manipulation.py:1759
   # TODO: Check if robot is in presentation region` marker. Touches
   `interfaces/moveit/object_manipulation.py` and the commander-side safety
   callback. → known-issues Open §B5.

### P2 — Wave 2 refactors

2. **WT-I · `robot_name` vs `group_name`.** Make `robot_name` the task-facing
   parameter; keep `group_name` a property of the controlled robot. Touches
   `tabletop_tasks/**`, `nodes/commander.py`,
   `interfaces/moveit/{object_manipulation,plan_and_execute}.py`. Now unblocked
   (its Wave-1 dependencies merged); rebase on current `main`. → known-issues Open §B3.
3. **WT-N · arm-lock terminology (mechanism-agnostic rename).** Reword the
   inaccurate "electromagnetic arm lock" wording and the `SetArmLock` /
   `*_arm_lock*` naming repo-wide (`interfaces/teensy.py`, `commander.py`,
   `tabletop_interfaces/**`, firmware comments, `commander.yaml`, `docs/**`) to
   be agnostic to the hold/detect mechanism (currently a button per hand).
   Large cross-cutting rename. → known-issues Open §B4.
4. **WT-P · retire the legacy Python bag converter.** Move
   `tabletop_rig/utils/rosbag.py` (`rosbag_to_csv`) to `deprecated/`, drop its
   `setup.py` entry point, and rewire the gaze-calibration scripts to consume
   CSVs produced by `tabletop_unbag` (`unbag`) instead of importing the Python
   utility to convert bags inline. (The `rosbag_convert` `tt-launch` target was
   already removed in this PR.) Independent of WT-I/WT-N (different files).
   → known-issues Open §B6.

> **Coordination:** WT-I and WT-N both edit `commander.py` and the manipulation
> interfaces — run them back-to-back and rebase the second on the first, don't
> run them blindly in parallel. WT-O also touches `object_manipulation.py`, so
> sequence it relative to WT-I. WT-P is file-independent of all three.

### P3 — Deferred feature

5. **`nodes/flic.py:323` → custom message.** Publish the Flic response on a
   dedicated `tabletop_interfaces` message instead of a generic type. Needs a new
   `.msg` + colcon rebuild. → known-issues Open §A2.

### P4 — "Decide later" markers (sweep with whichever worktree owns the file)

`compose.yaml:203` (`SYS_NICE`), `interfaces/moveit/moveit.py:465`,
`interfaces/moveit/plan_and_execute.py:628` (maybe revalidate),
`interfaces/ur.py:542`. (`object_manipulation.py:1759` "check presentation
region" is now tracked as the safety item WT-O above, not a P4 marker.)
→ known-issues Open §C.

### Not scheduled — open design decision

- **smooth-pursuit fetch vs. manual-attach.** `smooth_pursuit.py` keeps the
  `manually_attach_object` workaround and its `# TODO: FIX!!!` intentionally;
  whether to physically pick the object is a design call, not a bug. Revisit
  only if the experiment design changes. → known-issues Open §A1.

---

## 3. Priority tiers (original definitions)

- **P1** — quick, high-confidence bug fixes & doc inconsistencies (Wave 1, done).
- **P2** — important but gated (decision / hardware / more code).
- **P3** — feature updates / larger refactors.
- **P4** — optional cleanup (cosmetic / "decide later" markers).

---

## 4. Wave 1 worktrees (completed)

Each worktree below was one branch over a disjoint file set, merged in the PR
shown in Section 1. Retained for provenance; see the PRs and
`docs/known-issues.md` "Resolved in Wave 1" for the exact changes.

- **WT-A** (`#19`) — `plan_and_execute.py` margin param; `object_manipulation.py`
  reset honours `use_cache=False`.
- **WT-B** (`#25`) — `spin_until_future_complete` no longer leaks
  `ConditionReachedException`; `executors.py` uses the logger, not `print`.
- **WT-C** (`#20`) — `stop_program()` tracks its rclpy future across calls (P1).
  The P2 `safety_restart` recovery (dashboard reconnect, `ur.py::_reconnect`) is
  implemented and **validated on the real robot** (2026-06-30).
- **WT-D** (`#21`) — `manually_atatch_object` → `manually_attach_object` (+ call
  sites); `foraging.py` `release_arm` kept, its `# TODO: Remove!!!` removed;
  `smooth_pursuit.py` fetch decision kept open by design.
- **WT-E** (`#22`) — `*_elbow_joint` fix; deleted dead `base_link_name` /
  `moved_tolerance`; added `safe_to_execute.require_arm_locks` (default false);
  shared Flic MACs confirmed intentional.
- **WT-F** (`#23`) — `gaze_estimation_geometric.yaml` realigned to
  `gaze_estimation.yaml` (model block aside).
- **WT-G** (`#30`) — configurable arm-lock gate, debounce-init fix, ISR
  monotonic clock, pin-38 rationale, `UNRECOVERABLE_ERROR` rename.
  **Validated on the bench** (2026-06-30).
- **WT-H** (`#29`) — retired `rig.launch.py` to `deprecated/`; flattened
  `tasks.launch.py` to include `commander`/`rosbag` directly; silenced the
  `fallback_controllers` / `publish_robot_description_semantic` bringup warnings;
  resolved the `to_dict()` and `execution_duration_monitoring` TODOs.
- **WT-J** (`#24`) — `mingus` → runtime deps; gh-cli devcontainer feature;
  multi-platform `docker-bake.hcl`; `c_cpp_properties.json` cleanup.
- **WT-K** (`#27`) — `-h|--help` for the `tt-*` scripts.
- **WT-L** (`#28`) — `TeensySensor.msg` header; `deprecated/README.md`;
  `docs/guide/parameters.md`; FLIR GenICam reference; committed Foxglove layouts;
  setup-doc gaps.
- **WT-M** (`#26`) — eyelink TODOs resolved (stale-sample drain **validated on a
  live Eyelink**, 2026-06-30); `flic.py` custom-message TODO deferred (Section 2 · P3).

---

## 5. Maintainer decisions (answered & applied)

1. **Arm-lock safety gate** — not force-re-enabled; made configurable via
   `safe_to_execute.require_arm_locks` (default `false`). ✅ applied (#30/#22).
2. **`base_link_name` / `moved_tolerance`** — confirmed unused, deleted. Shared
   Flic MACs intentional, left alone. ✅ applied (#22).
3. **smooth-pursuit `fetch_object`** — not restored; TODO + known-issue kept as a
   design decision. `foraging.py` `release_arm` kept, its TODO removed.
   ✅ applied (#21).
4. **`gaze_estimation_geometric.yaml`** — aligned with `gaze_estimation.yaml`
   except model-creation parameters. ✅ applied (#23).

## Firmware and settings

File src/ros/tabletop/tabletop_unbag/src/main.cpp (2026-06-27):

// Copyright 2026 Jazlab
//
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
#include <algorithm>
#include <cctype>
#include <filesystem>
#include <iostream>
#include <stdexcept>
#include <string>
#include <vector>

#include "tabletop_unbag/unbagger.hpp"

namespace fs = std::filesystem;

namespace
{

void print_usage(const char* argv0)
{
  std::cout << "Usage: " << argv0
            << " BAG_DIR [options]\n\n"
               "Unbag a ROS 2 bag (MCAP) into per-topic outputs: CSV files for normal\n"
               "messages and image files for image topics. Each message type is routed to\n"
               "a handler that knows how to write it.\n\n"
               "Positional arguments:\n"
               "  BAG_DIR                 Directory containing the bag (its .mcap files and\n"
               "                          metadata.yaml).\n\n"
               "Common options:\n"
               "  -o, --output-dir DIR    Where to write outputs.\n"
               "                          Default: <parent of BAG_DIR>/unbag\n"
               "  --handlers H [H ...]    Handlers to enable (e.g. csv image). Topics whose\n"
               "                          type is not claimed by an enabled handler are\n"
               "                          skipped. Default: all handlers.\n"
               "  --topics T [T ...]      Only unbag these topics.\n"
               "  --exclude-topics T ...  Unbag all topics except these.\n"
               "                          (--topics and --exclude-topics are mutually\n"
               "                          exclusive.)\n"
               "  --overwrite             Delete previously unbagged output for the selected\n"
               "                          topics before writing. Without it, an interrupted\n"
               "                          run resumes where it left off.\n"
               "  --jobs N                Worker threads for the shared image-decoding pool\n"
               "                          (default: number of hardware threads). Each CSV\n"
               "                          topic also runs on its own consumer thread.\n"
               "  --opencv-threads N      Threads OpenCV uses internally per image decode\n"
               "                          (default 1). We already parallelize across images\n"
               "                          via --jobs, so 1 avoids oversubscribing cores; tune\n"
               "                          against --jobs on your machine. 0 lets OpenCV pick.\n"
               "  --storage-id ID         Storage plugin override (default: inferred from the\n"
               "                          bag metadata, reindexing first if metadata.yaml is\n"
               "                          missing; fallback to the installed default plugin).\n"
               "  -v, --verbose           Increase logging verbosity.\n"
               "  -h, --help              Show this help message and exit.\n\n"
               "csv handler options:\n"
               "  --csv-batch-size N      Rows buffered in memory before flushing to disk\n"
               "                          (default 1000).\n\n"
               "image handler options:\n"
               "  --image-encoding ENC    Target color encoding for decoded images\n"
               "                          (default bgr8; e.g. rgb8, mono8).\n"
               "  --image-format FMT      Output file format: keep|png|jpg|tiff (default\n"
               "                          keep). keep preserves the source container\n"
               "                          (compressed keeps its format, raw -> png); a\n"
               "                          specific format applies to all image topics (png\n"
               "                          avoids a lossy re-encode of compressed topics).\n";
}

/// Consume the values following a list-valued flag, stopping at the next flag
/// (an argument starting with '-') or the end of the argument list.
std::vector<std::string> consume_list(int argc, char** argv, int& i)
{
  std::vector<std::string> values;
  while (i + 1 < argc)
  {
    const std::string next = argv[i + 1];
    if (next.size() > 1 && next[0] == '-' && !std::isdigit(static_cast<unsigned char>(next[1])))
    {
      break;
    }
    values.push_back(next);
    ++i;
  }
  return values;
}

/// Strip trailing path separators so parent_path() of "a/b/" yields "a", not
/// "a/b".
std::string strip_trailing_slash(std::string path)
{
  while (path.size() > 1 && path.back() == '/')
  {
    path.pop_back();
  }
  return path;
}

}  // namespace

int main(int argc, char** argv)
{
  tabletop_unbag::UnbagOptions options;
  std::vector<std::string> positionals;
  std::string output_dir;
  bool have_topics = false;
  bool have_exclude = false;

  for (int i = 1; i < argc; ++i)
  {
    const std::string arg = argv[i];
    if (arg == "-h" || arg == "--help")
    {
      print_usage(argv[0]);
      return 0;
    }
    else if (arg == "-o" || arg == "--output-dir")
    {
      if (i + 1 >= argc)
      {
        std::cerr << "ERROR - " << arg << " requires a value\n";
        return 2;
      }
      output_dir = argv[++i];
    }
    else if (arg == "--handlers")
    {
      options.handlers = consume_list(argc, argv, i);
    }
    else if (arg == "--topics")
    {
      options.topics = consume_list(argc, argv, i);
      have_topics = true;
    }
    else if (arg == "--exclude-topics")
    {
      options.exclude_topics = consume_list(argc, argv, i);
      have_exclude = true;
    }
    else if (arg == "--overwrite")
    {
      options.overwrite = true;
    }
    else if (arg == "--csv-batch-size")
    {
      if (i + 1 >= argc)
      {
        std::cerr << "ERROR - " << arg << " requires a value\n";
        return 2;
      }
      try
      {
        const long long value = std::stoll(argv[++i]);
        if (value <= 0)
        {
          throw std::out_of_range("batch size must be positive");
        }
        options.csv.batch_size = static_cast<std::size_t>(value);
      }
      catch (const std::exception&)
      {
        std::cerr << "ERROR - --csv-batch-size requires a positive integer\n";
        return 2;
      }
    }
    else if (arg == "--jobs")
    {
      if (i + 1 >= argc)
      {
        std::cerr << "ERROR - " << arg << " requires a value\n";
        return 2;
      }
      try
      {
        const long long value = std::stoll(argv[++i]);
        if (value <= 0)
        {
          throw std::out_of_range("jobs must be positive");
        }
        options.jobs = static_cast<std::size_t>(value);
      }
      catch (const std::exception&)
      {
        std::cerr << "ERROR - --jobs requires a positive integer\n";
        return 2;
      }
    }
    else if (arg == "--opencv-threads")
    {
      if (i + 1 >= argc)
      {
        std::cerr << "ERROR - " << arg << " requires a value\n";
        return 2;
      }
      try
      {
        // 0 is allowed: it tells OpenCV to choose the thread count itself.
        const long long value = std::stoll(argv[++i]);
        if (value < 0)
        {
          throw std::out_of_range("opencv threads must be non-negative");
        }
        options.opencv_threads = static_cast<int>(value);
      }
      catch (const std::exception&)
      {
        std::cerr << "ERROR - --opencv-threads requires a non-negative integer\n";
        return 2;
      }
    }
    else if (arg == "--image-encoding")
    {
      if (i + 1 >= argc)
      {
        std::cerr << "ERROR - " << arg << " requires a value\n";
        return 2;
      }
      options.image.encoding = argv[++i];
    }
    else if (arg == "--image-format")
    {
      if (i + 1 >= argc)
      {
        std::cerr << "ERROR - " << arg << " requires a value\n";
        return 2;
      }
      options.image.format = argv[++i];
    }
    else if (arg == "--storage-id")
    {
      if (i + 1 >= argc)
      {
        std::cerr << "ERROR - " << arg << " requires a value\n";
        return 2;
      }
      options.storage_id = argv[++i];
    }
    else if (arg == "-v" || arg == "--verbose")
    {
      options.verbose = true;
    }
    else if (!arg.empty() && arg[0] == '-')
    {
      std::cerr << "ERROR - Unknown argument: " << arg << "\n";
      print_usage(argv[0]);
      return 2;
    }
    else
    {
      positionals.push_back(arg);
    }
  }

  // --- Validate. -------------------------------------------------------------
  if (positionals.empty())
  {
    std::cerr << "ERROR - A bag directory is required\n";
    print_usage(argv[0]);
    return 2;
  }
  if (positionals.size() > 1)
  {
    std::cerr << "ERROR - Expected a single bag directory, got " << positionals.size() << "\n";
    return 2;
  }
  const std::string bag_dir = positionals.front();

  if (have_topics && have_exclude)
  {
    std::cerr << "ERROR - --topics and --exclude-topics are mutually exclusive\n";
    return 2;
  }

  for (const auto& name : options.handlers)
  {
    const auto& valid = tabletop_unbag::handler_names();
    if (std::find(valid.begin(), valid.end(), name) == valid.end())
    {
      std::cerr << "ERROR - Unknown handler '" << name << "'. Valid handlers:";
      for (const auto& v : valid)
      {
        std::cerr << ' ' << v;
      }
      std::cerr << "\n";
      return 2;
    }
  }

  std::error_code ec;
  if (!fs::is_directory(bag_dir, ec))
  {
    std::cerr << "ERROR - Not a directory: " << bag_dir << "\n";
    return 1;
  }

  // --- Resolve the output directory. -----------------------------------------
  if (output_dir.empty())
  {
    const fs::path bag_path = strip_trailing_slash(bag_dir);
    fs::path parent = bag_path.parent_path();
    if (parent.empty())
    {
      parent = ".";
    }
    output_dir = (parent / "unbag").string();
  }

  try
  {
    tabletop_unbag::unbag(bag_dir, output_dir, options);
  }
  catch (const std::exception& e)
  {
    std::cerr << "ERROR - " << e.what() << "\n";
    return 1;
  }

  return 0;
}

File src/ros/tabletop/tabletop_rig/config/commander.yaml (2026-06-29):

# Parameter file for the /commander node (nodes/commander.py).
# Loaded by commander.launch.py; merged at runtime with
# /tmp/commander_overrides.yaml (per-session overrides, e.g. robot_mode).
#
# Lookup order (BaseInterface.param): per-interface key takes precedence,
# then falls back to the corresponding "common_*" key (dict values are
# deep-merged). Params declared "null" resolve to Python None.
/commander:
  ros__parameters:
    # Commander parameters

    # Selects mock vs. real UR hardware behaviour. Set automatically from
    # robot_mode at launch (true when robot_mode:=mock; false when
    # robot_mode:=real). Consumed ONLY by the per-arm manipulation stack — passed from
    # Commander to each URInterface and ObjectManipulationInterface:
    #   - URInterface: asserts each UR driver node is running in the matching
    #     mode (mock when true, real when false) and raises on mismatch; it
    #     does NOT skip any waits.
    #   - ObjectManipulationInterface: when true, skips the post-grasp
    #     effort-based object-attachment check (the object is assumed attached).
    # Does NOT affect the Teensy, Flic, or Eyelink interfaces
    simulate: true

    # Maximum seconds to wait for all interfaces to shut down cleanly.
    # shutdown_timeout: 3.0

    # --- Smooth-pursuit reward logic (Commander.smooth_pursuit_and_reward) ---
    # Used by the EyelinkInterface smooth_pursuit callback.
    smooth_pursuit:
      # Duration (seconds) of each individual reward pulse when pursuit is active.
      reward_duration: 0.1
      # Minimum interval (seconds) between consecutive reward pulses.
      reward_interval: 1.0
      # minimum ratio of smoothly pursuing feedback messages to total messages
      # to activate the reward
      reward_threshold_ratio: 0.8

    # --- Flic Bluetooth button registry (Commander.flic_response_time) ---
    # Maps logical object_id strings to Bluetooth MAC addresses of the
    # corresponding Flic 2 buttons.  Looked up as flic.bd_addrs.<object_id>
    # by nodes/commander.py line 920.  big_object_7 and small_object_0 share
    # the same MAC (90:88:a9:50:5f:b6) as big_object_3 — this is currently
    # only for testing purposes.
    flic:
      bd_addrs:
        big_object_0: 90:88:a9:50:5f:68
        big_object_1: 80:e4:da:7f:70:dc
        big_object_2: 80:e4:da:7f:6d:e5
        big_object_3: 90:88:a9:50:5f:b6
        big_object_4: 80:e4:da:7f:70:fb
        big_object_5: 90:88:a9:50:66:0d
        big_object_6: 80:e4:da:7e:5c:9d
        big_object_7: 90:88:a9:50:5f:b6
        small_object_0: 90:88:a9:50:5f:b6
        small_object_1: 90:88:a9:50:5f:db
        small_object_2: 90:88:a9:50:5d:f7
        small_object_3: 90:88:a9:50:5f:92
        small_object_4: 90:88:a9:50:7b:a3
        small_object_5: 90:88:a9:50:65:da
        small_object_6: 90:88:a9:50:63:08
        small_object_7: 90:88:a9:50:62:eb
        small_object_8: 90:88:a9:50:66:0f
        small_object_9: 90:88:a9:50:61:4e
        small_object_10: 90:88:a9:50:5f:ac
        small_object_11: 90:88:a9:50:60:11
        small_object_12: 90:88:a9:50:60:9f
        small_object_13: 90:88:a9:50:66:10
        small_object_14: 90:88:a9:50:7c:cc
        small_object_15: 90:88:a9:50:65:ff
        small_object_16: 90:88:a9:50:7d:8f
        small_object_17: 90:88:a9:50:5e:c2
        small_object_18: 90:88:a9:50:60:09
        small_object_19: 90:88:a9:50:61:a5
        small_object_20: 90:88:a9:50:5f:70
        small_object_21: 90:88:a9:50:7c:7a
        small_object_22: 90:88:a9:50:5f:87
        small_object_23: 90:88:a9:50:7c:9d
        small_object_24: 90:88:a9:50:7c:b1
        small_object_25: 90:88:a9:50:7c:ba
        small_object_26: 90:88:a9:50:75:07
        small_object_27: 90:88:a9:50:65:fb
        small_object_28: 90:88:a9:50:66:09
        small_object_29: 90:88:a9:50:5f:68

    # --- Manipulator wiring (Commander.__init__) ---
    # Maps logical robot names to the three interface instance names created
    # for each arm.  Commander iterates this dict to build ManipulationContextManagers;
    # the names here must match the parameter sections below.
    robot_interface_names:
      left_manipulator:
        ur_interface_name: left_ur_interface
        manipulation_interface_name: left_manipulation_interface
        manipulation_context_interface_name: left_manipulation_context_interface
      right_manipulator:
        ur_interface_name: right_ur_interface
        manipulation_interface_name: right_manipulation_interface
        manipulation_context_interface_name: right_manipulation_context_interface

    # Interface parameters
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

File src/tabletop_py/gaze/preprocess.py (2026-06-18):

"""Data preprocessing pipeline for gaze estimation calibration.

This module handles preprocessing of eye tracking (EyeLink) and motion
capture (OptiTrack) data for gaze estimation model training. It provides
functions for timestamp alignment, data cleaning, smoothing, and merging
multiple data streams.

The preprocessing pipeline:
1. Format timestamps from ROS bag exports
2. Standardize time ranges between data streams
3. Clean invalid/missing data points
4. Reindex and interpolate to common time grid
5. Apply smoothing (Savitzky-Golay filter)
6. Merge eye tracking and marker data

Constants:
    EYELINK_POS_COLS: Eye position column names for both eyes.
    EYELINK_DATA_COLS: Input features for model training.
    MARKER_DATA_COLS: Target position columns (3D marker position).

Functions:
    reindex_and_interpolate: Resample data to new time grid.
    verify_timestamps: Validate timestamp monotonicity and frequency.
    smooth_savgol: Apply Savitzky-Golay smoothing filter.
    clean_eyelink_data: Remove invalid eye tracking samples.
    clean_marker_data: Remove invalid marker samples.
    preprocess_data: Full preprocessing pipeline.
    main: CLI entry point.

Example:
    python -m tabletop_py.gaze.preprocess -d /path/to/session --visualize
"""

import logging
import os
from collections.abc import Mapping, MutableMapping
from copy import deepcopy
from typing import Any, Literal, Optional, cast

import numpy as np
import pandas as pd
import yaml
from scipy.signal import savgol_filter
from scipy.stats import zscore

from tabletop_py.gaze.visualize import (
    animate_2d_dots,
    plot_eyelink_markers,
)

try:
    from pylink.constants import MISSING_DATA
except ImportError:
    MISSING_DATA = -32768

logger = logging.getLogger(__name__)

pd.options.mode.copy_on_write = True


#: Column names for eye position data (both eyes, x and y)
EYELINK_POS_COLS = ["left_x", "left_y", "right_x", "right_y"]

#: Input feature columns for gaze estimation model
EYELINK_DATA_COLS = EYELINK_POS_COLS  # + ["left_pupil", "right_pupil"]

#: Column names for marker position data (x, y, z)
MARKER_POS_COLS = ["marker_x", "marker_y", "marker_z"]

#: Target output columns for gaze estimation model
MARKER_DATA_COLS = MARKER_POS_COLS


def verify_timestamps(
    df: pd.DataFrame, freq: float, *, freq_rtol: float, freq_var_tol: float
):
    """
    Verifies the integrity of the timestamps.

    Args:
        df: The data to verify.
        freq: The expected frequency of the data.
        freq_rtol: The relative tolerance for the frequency.
    """
    # Check that the timestamps are non-NAN and monotonically increasing
    for col in df.columns:
        if df[col].isna().any():
            raise ValueError(f"df[{col}] has NAN values")

        if not df[col].is_monotonic_increasing:
            raise ValueError(f"df[{col}] is not monotonically increasing")

        diff_mean = df[col].diff().mean()
        if not np.isclose(diff_mean, 1 / freq, rtol=freq_rtol):
            raise ValueError(
                f"{col} diff mean of {diff_mean:.6f} is not close to the expected value {1 / freq:.6f}"
            )

        diff_std = df[col].diff().std()
        if not np.isclose(diff_std, 0, atol=freq_var_tol):
            raise ValueError(
                f"{col} diff std of {diff_std:.6f} is not close to 0"
            )


def eyelink_array_to_samples(df: pd.DataFrame) -> pd.DataFrame:
    i = 0
    dfs: list[pd.DataFrame] = []
    while f"samples[{i}].header.stamp.sec" in df.columns:
        cols = filter(lambda col: f"samples[{i}]" in col, df.columns)
        new_df = df[cols]
        new_df.columns = [
            col.replace(f"samples[{i}].", "") for col in new_df.columns
        ]
        dfs.append(new_df)
        i += 1

    df = pd.concat(dfs, ignore_index=True)
    df["time"] = df["header.stamp.sec"] + df["header.stamp.nanosec"] / 1e9
    df = df.sort_values(by="time", axis=0)
    df = df.reset_index(drop=True)
    df = df.drop(columns="time")

    return df


def format_eyelink_columns(
    df: pd.DataFrame,
    *,
    freq: float,
    verify: bool = True,
    freq_rtol: float | None = None,
    freq_var_tol: float | None = None,
) -> pd.DataFrame:
    """
    Formats the timestamps to seconds and checks for monotonicity.

    Args:
        df: The eye tracker data.
        freq: The expected frequency of the data.
        verify: Whether to verify the timestamps and monotonicity.
        freq_rtol: The relative tolerance for the frequency.
        freq_var_tol: The absolute tolerance for the frequency.

    Returns:
        The formatted eye tracker data.
    """
    df = df.copy()

    # Convert ROS timestamp to seconds
    df["time"] = df["header.stamp.sec"] + df["header.stamp.nanosec"] / 1e9

    if verify:
        if freq_rtol is None or freq_var_tol is None:
            raise ValueError(
                "freq_rtol and freq_var_tol must be provided if verify is True"
            )

        time_cols = ["time", "eyelink_time"]

        # Convert timestamps to seconds
        df["eyelink_time"] = df["eyelink_time_ms"] / 1e3

        if "bag_time_ns" in df.columns:
            df["bag_time"] = df.bag_time_ns / 1e9
            time_cols.append("bag_time")

        # Verify the timestamps
        verify_timestamps(
            df[time_cols],  # type: ignore
            freq,
            freq_rtol=freq_rtol,
            freq_var_tol=freq_var_tol,
        )

    df = df[["time", *EYELINK_DATA_COLS]].astype(float)

    return df
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

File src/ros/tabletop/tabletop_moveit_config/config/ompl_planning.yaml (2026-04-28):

planning_plugins:
  - ompl_interface/OMPLPlanner
# The order of the elements in the adapter corresponds to the order they are processed by the motion planning pipeline.
request_adapters:
  - default_planning_request_adapters/ResolveConstraintFrames
  - default_planning_request_adapters/ValidateWorkspaceBounds
  - default_planning_request_adapters/CheckStartStateBounds
  - default_planning_request_adapters/CheckStartStateCollision
response_adapters:
  # - default_planning_response_adapters/AddTimeOptimalParameterization
  - default_planning_response_adapters/ValidateSolution
  # - default_planning_response_adapters/DisplayMotionPath

planner_configs:
  # Default planners
  AnytimePathShortening:
    type: geometric::AnytimePathShortening
    shortcut: true # Attempt to shortcut all new solution paths
    hybridize: true # Compute hybrid solution trajectories
    max_hybrid_paths: 24 # Number of hybrid paths generated per iteration
    num_planners: 4 # The number of default planners to use for planning
    planners: "" # A comma-separated list of planner types (e.g., "PRM,EST,RRTConnect"Optionally, planner parameters can be passed to change the default:"PRM[max_nearest_neighbors=5],EST[goal_bias=.5],RRT[range=10. goal_bias=.1]"
  SBL:
    type: geometric::SBL
    range: 0.0 # Max motion added to tree. ==> maxDistance_ default: 0.0, if 0.0, set on setup()
  EST:
    type: geometric::EST
    range: 0.0 # Max motion added to tree. ==> maxDistance_ default: 0.0, if 0.0 setup()
    goal_bias: 0.05 # When close to goal select goal, with this probability. default: 0.05
  LBKPIECE:
    type: geometric::LBKPIECE
    range: 0.0 # Max motion added to tree. ==> maxDistance_ default: 0.0, if 0.0, set on setup()
    border_fraction: 0.9 # Fraction of time focused on boarder default: 0.9
    min_valid_path_fraction: 0.5 # Accept partially valid moves above fraction. default: 0.5
  BKPIECE:
    type: geometric::BKPIECE
    range: 0.0 # Max motion added to tree. ==> maxDistance_ default: 0.0, if 0.0, set on setup()
    border_fraction: 0.9 # Fraction of time focused on boarder default: 0.9
    failed_expansion_score_factor: 0.5 # When extending motion fails, scale score by factor. default: 0.5
    min_valid_path_fraction: 0.5 # Accept partially valid moves above fraction. default: 0.5
  KPIECE:
    type: geometric::KPIECE
    range: 0.0 # Max motion added to tree. ==> maxDistance_ default: 0.0, if 0.0, set on setup()
    goal_bias: 0.05 # When close to goal select goal, with this probability. default: 0.05
    border_fraction: 0.9 # Fraction of time focused on boarder default: 0.9 (0.0,1.]
    failed_expansion_score_factor: 0.5 # When extending motion fails, scale score by factor. default: 0.5
    min_valid_path_fraction: 0.5 # Accept partially valid moves above fraction. default: 0.5
  RRT:
    type: geometric::RRT
    range: 0.0 # Max motion added to tree. ==> maxDistance_ default: 0.0, if 0.0, set on setup()
    goal_bias: 0.05 # When close to goal select goal, with this probability? default: 0.05
  RRTConnect:
    type: geometric::RRTConnect
    range: 0.0 # Max motion added to tree. ==> maxDistance_ default: 0.0, if 0.0, set on setup()
  RRTstar:
    type: geometric::RRTstar
    range: 0.0 # Max motion added to tree. ==> maxDistance_ default: 0.0, if 0.0, set on setup()
    goal_bias: 0.05 # When close to goal select goal, with this probability? default: 0.05
    delay_collision_checking: 1 # Stop collision checking as soon as C-free parent found. default 1
  TRRT:
    type: geometric::TRRT
    range: 0.0 # Max motion added to tree. ==> maxDistance_ default: 0.0, if 0.0, set on setup()
    goal_bias: 0.05 # When close to goal select goal, with this probability? default: 0.05
    max_states_failed: 10 # when to start increasing temp. default: 10
    temp_change_factor: 2.0 # how much to increase or decrease temp. default: 2.0
    min_temperature: 1e-9 # lower limit of temp change. default: 10e-10
    init_temperature: 1e-5 # initial temperature. default: 10e-6
    frountier_threshold: 0.0 # dist new state to nearest neighbor to disqualify as frontier. default: 0.0 set in setup()
    frountierNodeRatio: 0.1 # 1/10, or 1 nonfrontier for every 10 frontier. default: 0.1
    k_constant: 0.0 # value used to normalize expression. default: 0.0 set in setup()
  PRM:
    type: geometric::PRM
    max_nearest_neighbors: 10 # use k nearest neighbors. default: 10
  PRMstar:
    type: geometric::PRMstar
  FMT:
    type: geometric::FMT
    num_samples: 1000 # number of states that the planner should sample. default: 1000
    radius_multiplier: 1.1 # multiplier used for the nearest neighbors search radius. default: 1.1
    nearest_k: 1 # use Knearest strategy. default: 1
    cache_cc: 1 # use collision checking cache. default: 1
    heuristics: 0 # activate cost to go heuristics. default: 0
    extended_fmt: 1 # activate the extended FMT*: adding new samples if planner does not finish successfully. default: 1
  BFMT:
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

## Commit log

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2024-11-15 Tabletop server launch implementation complete, bug in build
    [base_0.obj, base_1.obj, calibration.yaml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]
2024-11-15 Tabletop server launch implementation done, bug in build
    [base_0.obj, base_1.obj, clavicle.stl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]
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2025-01-11 Added eef tool, tcp_pose_broadcaster seems to be interfering/overwriting /robot_description topic
    [tabletop.srdf.xacro, tabletop.urdf.xacro, tabletop_control.urdf.xacro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]
2025-01-11 Added end effector link to urdf to prevent robot safety mechanism from going off
    [tabletop.urdf.xacro, tabletop_control.urdf.xacro, tabletop_macro.srdf.xacro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]
2025-01-14 Planning with tool sphere collision object to prevent "clamping" error on robot, communication with robot established, robot following trajectory successfully
    [ur5e_calibration.yaml, ursim_calibration.yaml]
2025-01-14 Updated planning scene with floor object, now planning successfully with real robot (still clamping error on teach pendant)
2025-01-17 Added scene.dae file to URDF, planning with collision avoidance working, added x11 support as extended docker compose services, added custom rsp launch file and modularized urdf macros, reformatted .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
    [eef_macro.xacro, scene_macro.xacro, tabletop.urdf.xacro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]
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2025-01-21 Fixed velocity scaling params and pipeline param
    [commander.yaml, moveit_cpp.yaml]
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2025-02-05 Teensy flashed with microros and fully functional (sensors publishing at correct rate, sync pulses accurate and without noise, consistent), still to test services
    [main.cpp]
2025-02-05 Teensy working for all services and topics, sync pulse with jitter functional, cli interaction with arduino successful, build pipeline automated)
    [main.cpp]
2025-02-10 Running asyncio with error handling and thread safety
    [main.cpp, ompl_planning.yaml, utils.py]
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2025-02-12 Fix for exception in rclpy callback
    [joint_limits.yaml]
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2025-02-14 Loading of stls as collision objects working, scale wrong
    [tabletop_macro.srdf.xacro, trap_Link.stl, trapezoid near robot.csv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]
2025-02-18 Working Collision Object loading and planning scene saving. Now to figure out attaching and detaching objects
    [moveit_cpp.yaml, utils.py]
2025-02-19 Static and dynamic meshes loaded as collision objects with configurable paths, scaling, and individual poses
    [complex_object.stl, simple_object.stl, tabletop_macro.xacro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]
2025-02-20 Dynamic and static mesh loading, dimensions wrong
    [commander.yaml, utils.py]
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2025-02-23 Planning around objects in updated planning scene with collision objects, error with rviz materials
    [eef_macro.xacro, sphere_macro.xacro, tabletop_macro.srdf.xacro]
2025-02-24 Planning to and attaching to objects functional, errors on moving away with attached object
    [commander.yaml, moveit_cpp.yaml]
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2025-02-28 Refactored project structure and configuration files
    - Updated Docker, compose, and devcontainer configurations
    - Simplified ROS package and task configurations
    - Added new utility scripts for build, clean, and mesh manipulation
    - Removed deprecated nodes and services
    - Updated MoveIt and ROS package dependencies
    - Improved error handling and logging in core nodes
    [commander.yaml, main.cpp, moveit_cpp.yaml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]
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2025-03-27 Object retrieval from tool pocket (gripper). Linear pipeline configuration implemented, not working with pilz (not respecting allowed collision matrix)
    [commander.yaml, foraging_random.yaml, moveit_cpp.yaml]
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2025-03-31 Fetch object and return object planning fixed. Using OMPL APS with RRTC for long-distance planning and PILZ LIN for object retrieval and return motions. IK issues solved by caching post-attach state
    [joint_limits.yaml, tabletop_macro.srdf.xacro]
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2025-04-10 Revamped foraging.py to handle cross-phase hand fixation. ∙ Improved task api for commander ∙ Removed task group context manager ∙ Simplified error handling for service calls and tasks ∙ Flic buttons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
    [commander.yaml, foraging_random.yaml]
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2025-04-17 Now that we've gotten everything to work on the simple rig, it's time to tear it down.
    I was delirious while writing the last few commits so I spent a lot of time fixing my shitty code. In doing so I have written even shittier code, so keep that in mind as you read through this commit history Watters.
    Also note to self, stop the robot from smashing into things over and over.
    [commander.yaml, foraging_random.yaml, main.cpp]
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2025-05-05 Absolutely slept ros2 logging
    Literally though, by sleeping for a short time in each sample acquisition loop to allow for context switching
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2025-06-11 Fuzzing complete: - Fuzzy trajectory caching finally seems to work - Upgraded to sqlite3 for cache - Commander refactor: * Planning pipeline now accepts initialized planning component and request par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
    [tabletop_macro.srdf.xacro]
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2025-06-19 Added smoothing, fixed some small errors in detaching the object, refactored bin directory
    [cylinder_macro.xacro, eef.bak.stl, eef_macro.xacro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]
2025-06-26 Massive update that does nothing at all, new interface for teensy and flic and eyelink, teensy sensor causing issues when reading directly from it
    [commander.yaml, foraging_ordered.yaml, main.cpp]
2025-06-26 I fixed it yippee
    [commander.yaml]
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2025-07-22 Business may resume (flic and teensy now working, fixed robot joint velocity limit errors), however, robot base is moving, need to recalibrate or move it back somehow
    [joint_limits.yaml]
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2025-08-30 It's definitely not working
    [main.cpp]
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2025-11-18 How to kill a god (part 2.5, foraging through moveit collision detectors)
    [commander.yaml, foraging_ordered.yaml]
2025-11-26 Moved trajectory processing to plan request, simplified execution logic, fixed commander hanging on sigint
    [commander.yaml]
2025-11-27 God doesn't exist, and neither do I (part 15)
    [commander.yaml]
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2025-12-20 Object resetting largely done
    [commander.yaml, foraging_ordered.yaml]
2026-01-06 Cranked out some tests, need to figure out this ur calibration problem. Otherwise will hopefully develop a more robust test suite down the line so as not to rely on my dwindling memory
    [optitrack.yaml]
2026-01-09 Absolutely blasting through testing
    - Dashboard interface wildly improved
    - Robot base and object mount poses recalibrated
    - Dummy task for dummy easy testing
    - Various qol features
    - Real robot fixes/changes
    - Foraging vastly improved
    - Future workload increased twofold
    [tabletop_macro.xacro]
2026-01-09 Add comprehensive Google-style docstrings to tabletop_rig package
    Update documentation for all modules in tabletop_rig:
    - Module-level docstrings with purpose, features, and usage examples
    - Class docstrings with Attributes sections
    - Method/function docstrings with Args, Returns, and Raises
    - Inline comments for complex logic where needed
    Files documented:
    - exceptions.py: Exception hierarchy and error codes
    - executors.py: Custom asyncio-compatible ROS2 executors
    - utils/: logging, ros utilities, rosbag conversion
    - interfaces/: base, flic, eyelink, sound, teensy, dashboard
    - interfaces/moveit/: requests, cache, planning_scene,
    plan_and_execute, object_manipulation, moveit
    - nodes/: bas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
2026-01-09 Add Google-style docstrings to launch files and test module
    Launch files (tabletop_description):
    - rsp.launch.py: Module docstring, generate_launch_description(), urdf_save()
    - view_robot.launch.py: Module docstring, declare_arguments(), generate_launch_description()
    Launch files (tabletop_moveit_config):
    - moveit.launch.py: Module docstring, declare_arguments(), generate_launch_description()
    - ur_moveit.launch.py: Module docstring, generate_launch_description()
    Test files:
    - gaze_estimation_test.py: Module docstring, test class docstrings,
    helper function docstrings, fixture docstrings
2026-01-13 trac_ik, moveit2, and flir_camera_driver modules updated, improved build workflow, fixed flir build issues, flir cpu usage limited
    [foraging_ordered.yaml]
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2026-02-18 I think I fixed eyelink guys, I promise
    [preprocess.py]
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2026-03-04 Fixed some issues with trajectory cache (that I caused)
    [commander.yaml]
2026-03-04 Some object manipulation fixes with resetting the rig safely
    [commander.yaml]
2026-03-07 Some eyelink and optitrack fixes
    [predict.py, utils.py]
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2026-03-18 some rosbag and flir fixes
    [smooth_pursuit_spiral.yaml]
2026-03-25 Teensy safety laser fix
    [main.cpp]
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2026-03-27 Object attach and detach rectification, object attached detection not working
    [commander.yaml, foraging_ordered.yaml, foraging_random.yaml]
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2026-04-10 Object manipulation should work but doesn't
    [commander.yaml]
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2026-04-27 updated task and object reset config files
    [foraging_ordered.yaml, foraging_random.yaml, left_drawer.yaml]
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2026-05-21 spin reset
    [reset_station.step]
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2026-06-11 Add system_check node with FLIR camera synchronization check
    Adds a SystemCheck node to tabletop_rig for verifying live rig
    components. The first check (flir_sync) subscribes to the synchronized
    FLIR driver's per-camera meta topics, groups frames by header stamp
    and verifies both driver-level grouping (identical stamps, complete
    groups) and hardware-level sync (matching on-camera clock intervals
    across cameras).
    Also converts nodes/__init__.py to lazy (PEP 562) imports so that
    node entry points no longer pull in torch via the Eyelink import,
    and adds offline pytest coverage for the sync analysis.
2026-06-15 Add system architecture map and known-issues review notes
    docs/architecture.md is a conceptual dependency graph of the whole
    platform: infrastructure (bin scripts -> compose services -> env
    flow), the ROS runtime graph between containers, launch/config
    consumption, package import graph, code-level interface composition,
    and a symptom -> file troubleshooting table.
    docs/known-issues.md records code/config/doc discrepancies found
    during the review (missing multi_controllers.yaml, use_sim_time
    truthiness bug, broken tt-create-graph grep, stale CLAUDE.md and
    musings.md references). No code changes.
2026-06-15 Document tabletop_py package (docstrings only)
    Fills in missing module/class/function docstrings across gaze/, flic/
    and utils/, and fixes stale ones (predict.py module docstring was a
    copy of train.py's; evaluate() documented parameters that don't
    exist). Verified AST-identical to previous code apart from
    docstrings/comments.
    [calibrate.py, calibrate_camera.py, edf.py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]
2026-06-15 Document tabletop_rig nodes, interfaces, executors, utils
    Docstring-only pass over nodes/ (commander, eyelink, flic, mocks),
    non-moveit interfaces, executors.py, exceptions.py and utils/. Fixes
    stale module docstrings (flic.py listed parameters from the removed
    flicd client; mock node docstrings had wrong service names/topics).
    Reviewed against an AST-equivalence check: subagent attempts to
    rename Commander.manually_atatch_object and add return annotations
    were reverted (the typo'd name is load-bearing — two task modules
    call it; recorded in docs/known-issues.md instead).
2026-06-15 Reconcile README with current code after rebase
    Update the README to match the post-rebase codebase, using
    docs/architecture.md as the basis of truth:
    - CLI tables: drop host commands that no longer exist (tt-docker,
    tt-buildkit, tt-robot-network, tt-flicd, tt-udev-configure,
    tt-usbfs-configure, tt-cpu-speed-scaling-disable, tt-port-forward);
    add tt-build/tt-microros-build; move tt-clean to common;
    rename tt-teensy-build -> tt-microros-build.
    - Setup: host configure/install steps now run scripts/configure/*.sh
    and scripts/install/pulse.sh by path (not as tt-* commands);
    PlatformIO is preinstalled in the container.
    - tt-build options corrected (-c/--clean-tabletop, --clean-cmake,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
2026-06-15 Document tabletop_rig and tabletop_tasks config files
    Comment-only pass over the project-specific YAML configs (no values,
    keys, or structure changed; verified by parsing equality and a
    comment-only diff check):
    - commander.yaml: file header (param lookup order + override merge) and
    per-section docs tracing each block to its consuming interface
    (sound/teensy/ur/manipulation/moveit) with units (REP-103) and ranges.
    - object_reset/{left,right}_{drawer,spin}.yaml: reset-motion strategies,
    step-by-step motion sequences, frames, and collision-allowance rationale.
    - optitrack.yaml, update_rate.yaml: driver/controller-manager params.
    - tabletop_tasks smooth_pursuit_*/dummy and foraging_rando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
    [commander.yaml, foraging_random.yaml, left_drawer.yaml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]
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2026-06-15 Record firmware review findings in known-issues
    Adds the issues surfaced during the firmware documentation pass so the
    in-code "see docs/known-issues.md" references resolve:
    - #21 resetButtonAds() blocks the Flic main loop (agent-disconnect risk)
    - #22 Teensy BUTTON_STATE_PIN(36) vs LEFT_ARM_LOCK_STATE_PIN TODO(36)
    - #23 misspelled UNCRECOVERABLE_ERROR enum (cosmetic)
2026-06-15 Fill remaining public docstring gaps
    Docstring-only pass over public API that lacked docstrings, so the
    generated API reference is complete:
    - object_manipulation.py: PersistentState, ResetLoader, validate_and_lock,
    attach_link/current_manipulation_id properties, and the test-attach
    joint/wrench callbacks.
    - flic/scapy_client.py: main_async, wait_for_button(/_any/_closed), and the
    asyncio.Protocol overrides.
    - gaze/visualize.py: visualize_calibration, reindex_asof, animation callbacks.
    No code changed (AST-verified; ruff clean).
    [visualize.py]
2026-06-16 Add mkdocs documentation site
    Scaffold a Material-for-MkDocs site that combines conceptual pages with
    auto-generated API reference:
    - mkdocs.yml: Material theme, mermaid (architecture diagrams), and the
    mkdocstrings Python handler (griffe static analysis over the three
    package source trees — no ROS/hardware imports needed to build).
    - docs/: index, getting-started (setup/usage), guide (cli, configuration,
    tasks, hardware & safety, troubleshooting), and an API reference for
    tabletop_py / tabletop_rig / tabletop_tasks. architecture.md and
    known-issues.md are reused in place.
    - Conceptual pages synthesize the README, architecture.md, and musings.md,
    with all commands modernized t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
    [train.py]
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2026-06-18 build: replace host tt-launch wrapper and tt-dev-attach with tt-attach
    To run the gaze pipeline or any ros2 command not covered by tt-launch you
    need a shell in a container, so make that the supported path and drop the
    host tt-launch wrapper (container tt-launch is unchanged).
    Rename tt-dev-attach to tt-attach and rework it:
    - Takes an optional service argument (default: dev) and an optional
    -e/--use-existing flag.
    - By default runs `tt-compose run --rm <service> bash` (a fresh throwaway
    container) regardless of whether the service is already running, warning
    if it is. With -e it `exec`s into the running container instead.
    - No longer brings the service up first and no longer shells o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
2026-06-18 docs: document the TableTop network and drop robot-network.sh
    robot-network.sh only added a static IP to the first ethernet interface and
    was effectively non-functional as a complete setup step. Replace it with
    proper documentation in the Real Hardware Setup page.
    - Rename the concept from "robot network" to the "TableTop network": the
    wired LAN connects the host, the robots, and the EyeLink/OptiTrack hosts,
    not just the robots.
    - Document it conceptually so it can be configured from any UI (GNOME
    network settings) or the command line: the addressing scheme and subnet
    rule, a dedicated section on the network switch that bridges the devices,
    the host static-IP steps, and a firewall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
2026-06-18 docs: sweep repo references to the removed scripts/configure
    Point the remaining mentions of the host-config scripts at the new Real
    Hardware Setup documentation so nothing references the deleted files:
    - troubleshooting.md (FLIR cameras, Performance) now links to the host
    configuration procedures instead of invoking the scripts.
    - architecture.md and cli.md note that host configuration is documented,
    not shipped as scripts.
    - known-issues.md's command-migration note points at the docs.
    - CLAUDE.md's Key Configuration Files entry replaces scripts/configure
    with the real-hardware docs.
    Claude-Session: https://claude.ai/code/sessi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
2026-06-18 docs+build: address PR #15 review comments
    Build tooling:
    - tt-build: drop the `all` component (build colcon/microros/foxglove
    individually); add foxglove `-o/--output` (directory or *.foxe path)
    - Host wrappers (tt-attach, tt-build, tt-flir-reset) regenerate .env and
    call `docker compose` directly instead of going through tt-compose
    - tt-attach: reword the already-running warning; switch the running-check
    and shells to direct `docker compose`
    - Quote path/variable expansions across the bin/* scripts and setup.bash
    compose.yaml:
    - Inline `ipc: host` / `network_mode: host` and drop the x-common anchor
    - Trim the confusing trailing sentence from the builder comment
    Docs:
    - setup.md: dr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
2026-06-18 docs+build: fresh-eyes review fixes for PR #15
    - tt-build foxglove: resolve a relative -o/--output path against the
    caller's directory (make it absolute before cd-ing into the module dir)
    - setup.md: fix "user the NVIDIA Container Runtime" typo
    - teensy main.cpp: update the stale `tt-microros-build` build comment to
    `tt-build microros`
    - Revert musings.md: it is a historical notes file the PR intentionally
    leaves untouched (its stale commands are tracked in known-issues.md), so
    it should not be modernized piecemeal
    Claude-Session: https://claude.ai/code/session_012wFZvgfRJNmagFK86nmoGj
    [main.cpp]
2026-06-23 chore: remove obsolete and unused files
    Delete files that are no longer referenced by any active code, config, or
    documentation:
    - Stale dependency/notes dumps: deps/*.list, misc/* (blackfly node list,
    generated ROS graph markdown).
    - Single-arm leftovers superseded by the dual-arm stack: tabletop_description
    initial_positions/ur5e_calibration/ursim_calibration configs, rsp.launch.py
    and view_robot.launch.py, tabletop.urdf.xacro, the single-arm SRDF xacros,
    and the unused collision/eef.stl mesh (the visual mesh + primitive collision
    in eef_macro.xacro are what the model actually uses).
    - Unused MoveIt planning configs (chomp/stomp/isaac_ros_cumotion).
    - tabletop_rig leftovers: com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
    [eef.stl, rig_old.step, tabletop.srdf.xacro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]
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2026-06-23 fix: remove references to deprecated and removed components
    Update active code, configs, launch files, and build scripts to match the
    removed/archived files so the workspace still builds and launches:
    ursim removed (robot_mode is now mock|real only):
    - rig/commander/dual_ur launch choices and descriptions; dual_ur_calibrate is
    real-only; dropped the ursim-calibration branches (the files never existed)
    and the now-unused launch substitution imports.
    - compose.yaml: drop the dead ursim profile from novnc and refresh the header
    notes (ursim/flicd/flir-no-sync services are gone, archived in deprecated/).
    - commander.yaml comment.
    Single-arm -> dual-arm:
    - rig.launch.py now includes dual_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
    [joint_limits.yaml]
2026-06-23 docs: document deprecated components and sync docs with the cleanup
    - Add deprecated/README.md: a guided map of the archive (what each item was,
    where it came from, why it was retired, and what replaced it), so a curious
    maintainer can understand or revive any superseded subsystem.
    - CLAUDE.md: drop ursim from robot_mode/profiles, drop the ur launch target,
    note the Teensy is the only firmware now, and point to deprecated/.
    - docs/: remove ursim profile/robot_mode mentions, the tt-create-graph CLI
    row, the flic_micro build target, and the removed config rows; repoint
    view_robot.launch.py -> dual_view_robot.launch.py and the URCap install to
    share/; drop the retired flic.client/pi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
2026-06-23 fix: correct dual_view_robot docstring launch example
    Final-consistency fix: the launch file's own usage example still invoked the
    removed single-arm view_robot.launch.py; point it at dual_view_robot.launch.py.
    Claude-Session: https://claude.ai/code/session_011GNSq4YpqCp5VeRUVppbyB
2026-06-23 review: fix docstrings, drop calibrate robot_mode, tidy doc text
    - Generator docstring examples now match the real signatures: grouped_object_ids
    (a dict) instead of object_ids, occlude_prob for the random variant, and the
    skip_failed retry behavior (feedback is only ignored when skip_failed=True).
    - dual_ur_calibrate: drop the robot_mode argument entirely (calibration is
    real-only, so the option was meaningless).
    - tabletop_py.md: the package exposes tt-flic-scapy (tt-flic-client was removed).
    - real-hardware.md: copy the actual share/externalcontrol-1.0.5.urcap filename.
    Claude-Session: https://claude.ai/code/session_011GNSq4Yp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
2026-06-24 fix(config): correct elbow joint name, drop dead params, add require_arm_locks (#22)
    * fix(config): correct elbow joint name, drop dead params, add require_arm_locks
    - Fix typo: left_eblow_joint → left_elbow_joint,
    right_eblow_joint → right_elbow_joint (confirmed against SRDF and
    joint_limits.yaml in tabletop_moveit_config)
    - Remove dead keys confirmed to have no reader in tabletop_rig Python source
    (grepped src/ros/tabletop/tabletop_rig/tabletop_rig/):
    - *_manipulation_interface.trajectory_cache.base_link_name (left + right)
    - common_manipulation_interface.execution.moved_tolerance
    - Add require_arm_locks: false under teensy_interface.safe_to_execute;
    when true, motion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
    [commander.yaml]
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2026-06-25 refactor(launch): retire rig.launch.py, flatten tasks.launch.py, silence bringup warnings (#29)
    * refactor(launch): retire rig.launch.py, flatten tasks.launch.py, silence bringup warnings
    (1) Retire rig.launch.py: moved to deprecated/launch/rig.launch.py with entry
    in deprecated/README.md. The monolithic aggregator is obsolete now that each
    subsystem runs in its own Compose service. The `tt-launch rig` target and its
    CLAUDE.md mention have been removed from tt-launch; the build glob in
    setup.py already excludes it because it no longer lives in launch/.
    (2) Flatten tasks.launch.py: replaced the rig.launch.py include with direct
    IncludeLaunchDescription calls to commander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
    [dual_controllers.yaml]
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2026-06-29 fix(teensy): configurable arm-lock gate, debounce init, ISR-safe time, firmware tidy (#30)
    * fix(teensy): configurable arm-lock gate, debounce init, ISR-safe time, firmware tidy
    - TeensyInterface._msg_safe_to_execute: make the arm-lock gate configurable
    via the optional safe_to_execute.require_arm_locks parameter (read
    defensively; defaults to False when undeclared so behaviour is unchanged
    from the laser-only gate). Update docstrings. The commander.yaml entry is
    added by a separate branch (fix/commander-yaml-cleanup).
    - main.cpp: resolve the stale LEFT_ARM_LOCK_STATE_PIN "change back to 36"
    TODO with a clear rationale (pin 36 is BUTTON_STATE_PIN); pin numbers
    unchanged.
    - main.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
    [commander.yaml]
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
